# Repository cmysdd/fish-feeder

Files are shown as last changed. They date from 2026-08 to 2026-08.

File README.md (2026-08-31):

# ESP8266 + MixIO 远程鱼食投喂器

这是一个不自建服务器、不使用数据库、没有视频功能的远程鱼食投喂器。手机打开自己设计的网页，网页通过 MixIO 的 MQTT over WebSocket 接口发送命令；ESP8266 连接 MixIO MQTT 后驱动 MG90S 舵机完成投喂。

```text
手机自定义网页
    │ WSS 8084（加密）
    ▼
MixIO 免费主站
    ▲
    │ MQTT 1883 + HMAC 命令签名
    │
ESP8266 ── MG90S 舵机 ── 旋转量杯投喂机构
```

GitHub Pages 只负责免费托管静态 HTML、CSS 和 JavaScript，不运行后端函数。网页外观、按钮、状态显示和操作记录全部由本项目控制，不需要使用 MixIO 自带项目页面。

## 已实现功能

- 手机网页点击“立即投喂”执行一次完整动作
- 网页默认使用180°定位舵机，也可切换360°连续旋转舵机；两种模式都支持“去程→停留→回程”动作，180°模式可设置方向、角度和去/回程时间，参数保存在设备 EEPROM
- 最多 6 条设备本地定时计划，可设置时间、星期和启停状态；每条计划每次执行一次动作
- 定时计划保存在 ESP8266 EEPROM，手机关机或网页关闭后仍会执行
- MixIO WSS 实时连接和设备在线状态
- Wi-Fi 信号、剩余内存、固件版本、最近投喂时间
- 首次上电自建配网热点，Wi-Fi 凭据保存到 ESP8266 闪存
- 正常在线时从网页打开局域网设置页修改 Wi-Fi
- Wi-Fi 失效自动回退配网热点，支持双击 RST 强制重置
- 手机本地保存最近 30 条操作记录
- 每条命令带 UUID、签发时间、45 秒有效期和 HMAC-SHA256 签名
- ESP8266 EEPROM 保存最近命令、定时计划、最近投喂时间和 24 小时执行次数
- 防重复命令、防离线旧命令、防短时间连续投喂
- MQTT 断线自动重连、遗嘱消息和状态查询
- 舵机执行前先保存安全状态，执行中断电也不会重复运行同一命令
- 参数面板提供签名的“测试当前舵机”命令，不占用投喂次数，便于排查180°舵机接线和角度设置
- 多手机私密授权链接，导入后自动清除地址栏凭据
- 移动端计划卡片、操作提示、回到前台自动刷新和成功振动反馈

## 文档入口

- [完整项目方案](docs/project-plan.md)
- [硬件采购、供电、接线和机械结构](docs/hardware.md)
- [180° SG90 可打印机械结构](mechanical/README.md)
- [MixIO 注册、项目和主题配置](docs/mixio-setup.md)
- [GitHub Pages 部署、Arduino 烧录和首次联调](docs/deployment.md)
- [MQTT 消息协议和安全设计](docs/protocol.md)
- [测试与验收清单](docs/test-plan.md)

## 工程目录

```text
index.html                         手机控制台页面
styles.css                        响应式界面样式
app.js                            MixIO WSS、签名、状态和历史记录
.github/workflows/deploy-pages.yml GitHub Pages 自动部署
firmware/esp8266_fish_feeder/     ESP8266 Arduino 固件
docs/                             完整实施文档
```

## 最短落地路径

1. 购买 NodeMCU ESP8266、MG90S、5V 2A 电源和 1000uF 电容。
2. 注册 MixIO 账号并创建私有账号项目，记录用户名、项目名和项目密码。
3. 在第一台手机的“手机授权”中填写项目密码和命令签名密钥。
4. 其他可信手机可通过“复制授权链接”一次性导入相同配置；链接等同于钥匙，不要公开。
5. 按文档接线，烧录固件；Wi-Fi 不写进代码，首次上电用设备热点配置。
6. 把本目录推送到 GitHub，启用 GitHub Pages，手机使用生产 HTTPS 地址。
7. 在网页新增定时计划，等待设备回传并关闭网页验证自动执行。
8. 完成至少 100 次空载和装粮测试后再无人值守运行。

## 成本与限制

软件路线可以不产生固定月费，但 MixIO 和 GitHub Pages 的免费政策可能调整。硬件预计约 45～100 元，取决于是否已有 ESP8266、电源和机械外壳。

MixIO 为 ESP8266 提供的标准 MQTT 端口是 1883，设备到 MixIO 的传输不加密。本项目用额外的 HMAC 命令签名防止伪造投喂命令，但不能隐藏状态数据，也不能阻止网络层拒绝服务。更高安全等级需要自建 TLS MQTT、家庭 VPN，或改用能够稳定运行 WSS/TLS 的方案。

“投喂完成”表示舵机动作序列完成，不代表传感器已经确认鱼粮落下。长期无人值守版本应增加落料检测或称重反馈。

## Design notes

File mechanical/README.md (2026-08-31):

# SG90 180 度定量鱼食器机械结构 v2

这是本项目可直接打印的机械结构，使用 SG90 180 度定位舵机和偏心定量转盘：

```text
关闭位：料仓 -> 进粮口 -> 转盘定量孔
投喂位：转盘旋转 180 度 -> 定量孔对准落粮口 -> 导流嘴 -> 鱼缸
复位：  转盘反向旋转 180 度，重新装满定量孔
```

## 直接打印的 STL

将 [`stl`](stl) 文件夹发给打印者即可。里面是 6 个独立、已经按打印方向摆放的零件：

- `base.stl`：转盘底座，90 x 90 x 13 mm
- `rotor.stl`：固定容积转盘，直径 60.8 mm、厚 9 mm
- `hopper.stl`：约 600 mL 鱼粮仓和腔体上盖
- `lid.stl`：带防雨外沿的可拆上盖
- `servo_bracket.stl`：SG90 穿板支架，带安装调节槽
- `outlet_chute.stl`：压入式落粮导流嘴

这些 STL 均已检查为封闭、单体、法线一致的网格。不要把装配预览导出后打印。

参数化源文件是 [`fish_feeder_v1.scad`](fish_feeder_v1.scad)。以后要改容量或间隙时，用 OpenSCAD 修改后重新导出。默认定量孔直径 19 mm、深 9 mm，几何容积约 2.55 mL。

## 打印要求

优先用 PETG；长期室外日晒建议 ASA。PLA 只适合室内试装。

- 0.4 mm 喷嘴，0.20 mm 层高
- 底座、转盘、舵机支架：4 道墙、5 层顶底、40% 填充
- 料仓、盖子、导流嘴：3 道墙、5 层顶底、20% 填充
- 不缩放模型，单位必须是 mm
- 所有 STL 已放到打印平面，通常不需要支撑
- 料仓需要至少 120 x 100 mm 的打印平台
- 转盘与底座优先一起打印，材料和收缩率应保持一致

鱼粮接触件不等于食品级。打印后清理毛刺和线丝；需要更严格的食品接触要求时，加可拆洗的食品级内衬，不要在粮道里使用会脱落的涂层。

## 五金

- SG90 180 度定位舵机 1 个
- SG90 原装圆形或十字舵机臂 1 个，中心螺丝 1 个
- M3 x 30 螺丝、垫片和防松螺母各 4 个，用于夹紧料仓法兰、底座和舵机支架
- M2 x 8 螺丝和螺母 2 个，用于固定 SG90 耳片
- M2 x 6 自攻螺丝 2 个，用于把原装舵机臂固定到转盘底部
- 0.5 mm PET 垫片或薄食品级硅胶片，用于需要时微调转盘轴向间隙
- 食品级中性硅胶少量，只用于固定导流嘴外缘，不进入粮道
- 1000 uF 电解电容 1 个，靠近舵机 5V 和 GND
- IP65 成品防水盒 1 个，单独容纳 NodeMCU、电源接线和电容

## 装配

1. 将 SG90 从舵机支架下方穿入，输出轴对准底座中心。用两个 M2 螺丝穿过舵机耳片和支架调节槽固定，暂时不要拧死。
2. 用网页把舵机移动到关闭角度，建议先设为 10 度。安装原装舵机臂，确认舵机不会顶到机械限位。
3. 把舵机支架放在底座下方。输出轴和舵机臂从底座中心孔进入转盘腔。
4. 将转盘放入圆形腔体，定量孔朝向料仓侧的进粮位置。舵机臂嵌入转盘底部 32.5 mm 凹槽，用两颗 M2 x 6 自攻螺丝固定。
5. 手动检查转盘四周间隙。默认径向间隙 0.65 mm，上下各约 0.5 mm；转盘必须能转动，但不能明显上下晃动。
6. 放上料仓，使法兰孔、底座孔和支架孔对齐。四颗 M3 x 30 螺丝从上到下穿过，使用垫片和防松螺母均匀锁紧。
7. 把导流嘴从底座下方压入落粮口。试装合适后，只在外圈接缝点少量中性硅胶，保持内部粮道干净。
8. 装上盖子。电子部分放入旁边的 IP65 盒，舵机线和电源线通过 PG7/PG9 防水接头进入。

## 首次校准

1. 空仓测试：网页选择 180 度舵机，关闭角度先设 10 度，投喂角度先设 170 度，去程和回程各 1000 ms。
2. 检查关闭位：转盘定量孔必须完整位于料仓进粮口下方。
3. 检查投喂位：转盘转动后，定量孔必须完整位于底座落粮口上方。
4. 若两个位置均偏向同一侧，松开舵机臂中心螺丝，重新安装舵机臂；不要用软件角度强行顶住舵机限位。
5. 加入少量鱼粮连续测试 20 次。若转盘刮擦，用 0.5 mm PET 垫片微调料仓法兰；若颗粒进入转盘边缘，先清理毛刺，不要盲目扩大间隙。
6. 对 20 次投喂称重，确认平均重量后再装满粮仓。鱼粮密度不同，2.55 mL 不等于固定克数。
7. 装粮连续运行至少 100 次，确认不夹粮、舵机不过热、ESP8266 不重启，再进行无人值守测试。

## 打印前必须确认

SG90 克隆件的外壳、耳片孔距和输出轴高度可能相差 0.5-1.5 mm。建议先让朋友只打印 `servo_bracket.stl` 和 `rotor.stl` 做舵机试装，再打印其余大件。若舵机轴高度不足，可在支架与底座之间加薄垫片；若舵机臂与转盘凹槽不匹配，应修改源文件中的凹槽尺寸，不能强行压入。

这版没有位置或落料传感器，网页显示“动作完成”代表舵机程序执行完成，不代表鱼粮一定落下。无人长期运行前仍需做堵粮和断电恢复测试。

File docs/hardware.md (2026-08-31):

# 硬件采购、供电、接线和机械结构

## 1. 最小采购清单

| 数量 | 模块 | 推荐规格 | 参考用途 |
|---:|---|---|---|
| 1 | ESP8266 开发板 | NodeMCU ESP-12E/ESP-12F，CH340 或 CP2102 | Wi-Fi 和逻辑控制 |
| 1 | 舵机 | SG90 180°定位舵机（推荐）或360°连续旋转舵机 | 驱动旋转量杯 |
| 1 | 电源 | 稳压 5V 2A | 给开发板和舵机供电 |
| 1 | 电解电容 | 1000uF，耐压 10V 或更高 | 抑制舵机启动压降 |
| 若干 | 杜邦线或接线端子 | 按模块接口选择 | 信号和供电连接 |
| 1 | USB 数据线 | 必须支持数据传输 | 固件烧录 |
| 1 | 投喂机械件 | 旋转量杯、粮仓、固定支架 | 定量落料 |

连续旋转舵机只能控制方向和速度，不能直接知道绝对角度，因此本项目用运行时间估算角度并自动反转回位；如果需要精确定位，选择180°定位舵机或增加位置传感器。若机械负载较大，选带金属齿轮、额定5V的连续舵机。

## 2. 接线表

舵机常见线色（以你手上标签为准）：

| 舵机线 | 连接位置 |
|---|---|
| 棕色或黑色 | 5V 电源 GND |
| 红色 | 5V 电源正极 |
| 橙色或黄色 | NodeMCU D1（GPIO5） |

NodeMCU GND 必须与舵机电源 GND 连接在一起，否则舵机信号没有共同参考电位。

```text
NodeMCU D1 / GPIO5 ───────────── 舵机信号线

5V 电源正极 ──┬─────────────── 舵机红线
              └─────────────── NodeMCU VIN/5V

5V 电源负极 ──┬─────────────── 舵机棕/黑线
              └─────────────── NodeMCU GND

1000uF 电容接在舵机附近的 5V 与 GND 之间
电容正极接 5V，带条纹的负极接 GND
```

ESP8266 的 3.3V GPIO 信号通常可以直接控制 MG90S，但不能使用 ESP8266 的 3.3V 引脚给舵机供电。MG90S 堵转或快速启动时电流可能明显升高，必须使用稳定的外部 5V 电源。

### 配网重置按键

本固件默认使用 NodeMCU 的 `FLASH` 按键（GPIO0/D3）作为强制配网输入，不需要额外购买按键。设备正常运行时，按住 `FLASH`，再按一下 `RST`，松开后会清除已保存 Wi-Fi 并开启 `fish-feeder-xxxx` 配置热点。也可以快速连续按两次 `RST` 触发同样的配网模式。不要在烧录时长按 `FLASH`，否则开发板可能进入下载模式。

如果你的板子没有可用的 `FLASH` 键，可以在 `D3` 和 `GND` 之间接一个常开轻触按键，并在上电/复位时按住它。

## 3. 烧录和正式运行时的供电

### 烧录阶段

1. USB 只给 NodeMCU 供电和传输数据。
2. 舵机使用独立 5V 电源。
3. 舵机电源 GND 与 NodeMCU GND 共地。
4. 不要把外部 5V 正极再接到 NodeMCU VIN，避免两路 5V 电源互相回灌。

### 正式运行

拔掉电脑 USB 后，可以使用同一只 5V 2A 电源并联给 NodeMCU VIN/5V 和舵机供电。不同 NodeMCU 克隆板的电源保护方式不同，正式运行时不要同时插着电脑 USB 和外部 VIN 供电。

## 4. 机械结构选择

### 推荐：旋转量杯

```text
上方粮仓
   ↓
[量杯处于装粮位置]  ← SERVO_CLOSED_ANGLE
   │ 舵机旋转
[量杯处于倒粮位置]  ← SERVO_OPEN_ANGLE
   ↓
鱼缸
```

量杯的容积决定每次动作的鱼粮量。当前网页每次只执行一次装粮—倒粮—回位动作。

优点：

- 出粮量主要由量杯容积和机械结构决定。
- 180°普通舵机即可完成。
- 回位后自动准备下一份。
- 软件不需要根据鱼粮流速计算开门时间。

### 不推荐：单纯翻板闸门

闸门结构虽然最简单，但每次落料量会受颗粒大小、仓内压力、湿度和打开时间影响。鱼粮受潮后容易形成架桥，舵机动作完成却没有实际落料。

## 5. 舵机角度校准

本项目针对你的 180° SG90，推荐使用仓库中的参数化机械结构：[mechanical/README.md](../mechanical/README.md)。它使用固定容积转子量杯，转子孔先在上方装粮，再转到下方出粮口，避免 SG90 直接承受整仓鱼粮压力。

固件默认值（也可以在网页“投喂参数”中修改并保存到设备）：

```cpp
#define SERVO_CLOSED_ANGLE 90
#define SERVO_OPEN_ANGLE 180
#define SERVO_OPEN_MS 550
#define SERVO_SETTLE_MS 450
#define SERVO_MODE_DEFAULT 1
#define SERVO_POSITIONAL_MOVE_MS 1000UL
#define SERVO_ACTION_PAUSE_MS 1000UL
#define SERVO_POSITIONAL_RETURN_MS 1000UL
#define SERVO_CONTINUOUS_TURN_DEGREES 90
#define SERVO_CONTINUOUS_MS_PER_REV 4000UL
#define SERVO_CONTINUOUS_FORWARD_US 1700
#define SERVO_CONTINUOUS_REVERSE_US 1300
#define SERVO_CONTINUOUS_STOP_US 1500
```

网页默认使用180°定位舵机模式。对于机械转子量杯，先把关闭角度校准到转子孔对准上方装粮口，再把打开角度校准到孔对准下方出粮口，建议先用10°和170°，避免长期顶住舵机两端。180°定位模式使用“起始位置 + 方向 + 相对角度”，并以小步插值控制去程和回程时间。顺逆时针会受舵机安装方向影响，首次必须空载确认。360°连续舵机仍可手动切换，但不适合这套精确定量转子。

当前固件在180°模式使用500～2400us定位脉宽，以覆盖常见SG90的完整机械行程。保存180°模式参数时，设备会立即移动到起始位置；投喂时再执行“去程→停留→回程”。设定时间不能突破舵机自身速度上限：如果负载下90°实际至少需要1.3秒，即使网页填写1秒也无法让舵机物理上更快。如果网页测试完全没有动作，烧录 `firmware/servo_diagnostic/servo_diagnostic.ino` 排查。

第一次测试时不要安装舵臂：

1. 连续模式烧录后上电，舵机应保持停止，不应自行转动。
2. 先不装鱼粮，设置一圈耗时并测试180°转动，按实际转速微调。
3. 安装量杯后，用少量鱼粮测试一次出粮，调整转动角度和方向。
4. 如果切换到180°模式，断电后安装舵臂到关闭位置，再逐步调整两个定位角度。
5. 连续舵机停止脉宽通常约1500us；若仍慢慢转，用高级校准把停止脉宽调整到实际静止值。

不要依靠舵机堵转作为机械限位。长期堵转会导致电流上升、齿轮磨损和 ESP8266 重启。

## 6. 粮仓与环境

- 粮仓使用食品接触安全、无异味的材料。
- 增加密封盖和干燥剂空间，避免鱼缸水汽进入。
- 出粮口远离过滤泵水花和增氧气泡。
- 电路板和接线端子放在鱼缸水线以上。
- 电源线做拉力缓解，不能依靠杜邦线悬挂设备。
- 正式使用时采用螺丝端子或焊接，不使用松动的面包板连接。

## 7. 建议的第二阶段传感器

| 传感器 | 作用 | 优先级 |
|---|---|---|
| 槽型光电开关 | 检测量杯是否回到原位 | 高 |
| 对射光电或落料传感器 | 判断是否真的有鱼粮落下 | 高 |
| 1kg 称重传感器 + HX711 | 估算粮仓余量 | 中 |
| DS18B20 防水探头 | 读取鱼缸水温 | 中 |
| 漏水传感器 | 鱼缸附近积水报警 | 中 |

第一版没有位置和落料反馈，因此网页中的“完成”仅表示舵机动作序列执行完毕。

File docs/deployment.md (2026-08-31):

# 从烧录到 GitHub Pages 上线：完整部署教程

本项目采用“手机网页直连 MixIO + ESP8266 本地执行”的结构。GitHub Pages 只托管静态网页，不保存 MixIO 项目密码、命令签名密钥、计划表或操作记录。定时计划保存在 ESP8266 的 EEPROM 中，手机和网页关闭后仍会运行。

## 1. 当前项目已经准备好的内容

当前工作区已经完成：

- MixIO 用户名、项目名、项目密码和命令签名密钥配置。
- MixIO 项目密码和命令签名密钥写入本机私密 `config.h`。
- Wi-Fi 不写入源码，首次上电通过设备自己的配置热点写入闪存。
- `config.h` 已加入 `.gitignore`，不会提交到 Git。
- 私密 `config.h` 已加入 `.gitignore`，不会上传到 GitHub。
- 网页支持手动投喂、设备状态、最多 6 条定时计划和多手机授权。

你不需要修改固件里的 Wi-Fi 字符串；首次上电按下面的配网步骤填写。不要把私密 `config.h` 发到公开仓库或论坛。

## 2. 安装 Arduino IDE 和开发板

1. 安装 Arduino IDE 2.x。
2. 打开“文件 → 首选项”。
3. 在“附加开发板管理器网址”加入：

```text
https://arduino.esp8266.com/stable/package_esp8266com_index.json
```

4. 打开“工具 → 开发板 → 开发板管理器”。
5. 搜索并安装 `esp8266 by ESP8266 Community` 的稳定 3.x 版本。
6. 打开“库管理器”，安装：

| 库 | 建议版本 |
|---|---|
| ArduinoJson by Benoit Blanchon | 6.21.x，或确认兼容的更新版 |
| PubSubClient by Nick O'Leary | 2.8 或更新稳定版 |

`Servo`、`EEPROM`、`ESP8266WiFi`、NTP 时间和 BearSSL 随 ESP8266 开发板包提供。

## 3. 准备私密固件配置

打开：

```text
firmware/esp8266_fish_feeder/config.h
```

MixIO 信息和命令签名密钥已经在本机私密 `config.h` 中。Wi-Fi 两行保持空字符串即可：

```cpp
#define WIFI_SSID ""
#define WIFI_PASSWORD ""
```

注意：

- ESP8266 只能连接 2.4GHz Wi-Fi。
- Wi-Fi 名称区分大小写。
- 如果路由器把 2.4GHz 和 5GHz 合并为同一名称，一般可以使用；首次联调失败时建议临时分开名称。
- 其他 MixIO 和签名配置已经写好，不要只改固件而不更新授权手机。

## 4. 接线和烧录

首次烧录建议先断开舵机，只连接 NodeMCU USB：

1. 使用支持数据传输的 USB 线连接电脑。
2. Arduino IDE 打开：

```text
firmware/esp8266_fish_feeder/esp8266_fish_feeder.ino
```

3. 开发板选择 `NodeMCU 1.0 (ESP-12E Module)`。
4. 选择正确的 COM 端口。
5. Upload Speed 先选择 `115200`。
6. CPU Frequency 使用 `80 MHz`。
7. Flash Size 使用开发板默认的 4MB 选项即可。
8. 点击“验证”；成功后点击“上传”。
9. 打开串口监视器，波特率选择 `115200`。

首次没有 Wi-Fi 时，串口日志应包含：

```text
Wi-Fi configuration mode
Setup SSID: fish-feeder-xxxx
Open: http://192.168.4.1
```

填写 Wi-Fi 后，设备重启并连接成功时日志应包含：

```text
ESP8266 servo fish feeder starting
Wi-Fi connected, IP: ...
Connecting to MixIO MQTT...
MixIO MQTT connected
```

升级到当前固件时 EEPROM 数据结构会自动初始化一次；如果结构版本变化，旧的测试计数和计划被清空属于正常现象。

## 5. 首次配网和重置配网

1. 烧录后上电，手机连接设备热点 `fish-feeder-xxxx`，密码是 `fish8266`。
2. 打开 `http://192.168.4.1`；若手机弹出“此网络无互联网”，选择继续保持连接。
3. 填写家里的 2.4GHz Wi-Fi 名称和密码，点击“保存并连接”。设备会把信息写入 EEPROM/闪存并自动重启。
4. 以后断电、重启都不需要重新填写。正常联网时，网页状态卡片会显示局域网 IP，点击“打开 Wi-Fi 设置”即可在同一家庭 Wi-Fi 内修改。
5. 如果旧 Wi-Fi 改名或失效，设备尝试约 20 秒后自动开启配置热点。也可以双击 NodeMCU 的 `RST`，或按住 `FLASH` 再按 `RST`，清除旧凭据并进入配网。
6. 配网设置页是局域网管理页；不要把设备热点密码和局域网地址发到公共群组。

注意：设备已经成功 NTP 校时后，即使 MixIO 暂时不可达，已保存的计划仍可继续执行；如果设备重启后完全没有网络，时间尚未校准，计划会等联网校时后再执行。

## 6. 连接 MG90S 舵机

NodeMCU D1/GPIO5 连接舵机信号线。舵机使用独立稳定的 5V 2A 电源，NodeMCU GND 和舵机电源 GND 必须共地。舵机附近并联一个 1000uF 电解电容。

首次动作测试不要安装鱼粮：

1. 先空载通电。
2. 确认舵机回到关闭角度后停止。
3. 如果舵机持续嗡鸣，立即断电并缩小开关角度。
4. ESP8266 在舵机动作时重启，优先检查 5V 电源、电容和共地，不要用软件延时掩盖供电问题。

## 7. 本地预览网页

当前项目可通过本地静态服务器预览。浏览器地址类似：

```text
http://127.0.0.1:4173/
```

本地 HTTP 页面可能因浏览器安全策略无法使用剪贴板或 Web Crypto 的部分能力，最终测试使用 GitHub Pages 提供的 HTTPS 地址。

## 8. 部署到 GitHub Pages

网页没有构建步骤、数据库和环境变量。项目已经包含 `.github/workflows/deploy-pages.yml`，推送到 `main` 分支后会自动发布。

### 8.1 创建仓库并上传

1. 在 GitHub 新建一个仓库，例如 `fish-feeder`。
2. 想零成本使用 GitHub Pages 时，仓库可设为 `Public`；私密 `firmware/esp8266_fish_feeder/config.h` 仍绝不能提交。若使用私有仓库，请确认你的 GitHub 账号计划支持 Pages。
3. 在 PowerShell 中执行：

```powershell
cd C:\Users\Administrator\Desktop\硬件开发\fish-feeder
git init
git branch -M main
git add .
git status
git commit -m "Initial fish feeder page"
git remote add origin https://github.com/你的用户名/fish-feeder.git
git push -u origin main
```

执行 `git status` 时，不能看到以下文件：

- `firmware/esp8266_fish_feeder/config.h`
- 任何包含 MixIO 项目密码或命令签名密钥的私密备份文件

### 8.2 启用 GitHub Pages

1. 打开 GitHub 仓库的 `Settings → Pages`。
2. 在 `Build and deployment` 中选择 `GitHub Actions`。
3. 回到 `Actions` 页面，等待 `Deploy fish feeder page` 工作流完成。
4. 部署地址一般是：

```text
https://你的用户名.github.io/fish-feeder/
```

以后更新网页只需：

```powershell
git add .
git commit -m "Update fish feeder page"
git push
```

## 9. 第一台手机授权

1. 用手机打开 GitHub Pages 的 HTTPS 地址。
2. 点击右上角“手机授权”。
3. 用户名和项目名已经预填。
4. 输入 MixIO 项目密码。
5. 输入与固件 `COMMAND_SECRET` 完全一致的命令签名密钥。
6. 保持“保存在当前浏览器中”选中。
7. 点击“保存并连接”。

这些信息只写入当前域名的浏览器存储，并由手机直接用于连接 MixIO WSS。GitHub Pages 不会收到这些字段。

本地预览地址与 GitHub Pages 地址属于不同网站，浏览器存储不会互通，因此生产地址第一次打开时仍需授权一次。

## 10. 授权其他手机

第一台手机连接成功后：

1. 打开“手机授权”。
2. 点击“复制授权链接”。
3. 通过私聊发送给可信的人。
4. 对方打开链接后，网页自动把配置保存到对方手机。
5. 地址栏中的 `#config=...` 会立即被清除。

授权链接本身等同于项目密码和签名密钥。不要发送到群聊、朋友圈、公开笔记或短链接平台。需要撤销所有旧授权时，同时更换 MixIO 项目密码和命令签名密钥，然后重新烧录并重新授权手机。

## 11. 测试手动投喂

1. 页面顶部 MixIO 显示“已连接”。
2. 投喂器显示“在线”。
3. 点击“请求状态”，检查 Wi-Fi 信号、固件版本和设备时间。
4. 不放鱼粮，点击“立即投喂”；每次点击只执行一次完整动作。
5. 页面应依次显示命令发送、设备执行和投喂完成。
6. 一分钟内再次投喂，应被安全间隔拒绝。
7. 完成空载测试后，再安装少量鱼粮测试真实出粮量。

## 11.1 设置舵机角度和投喂限制

设备升级到固件 `1.5.3` 后，网页会显示完整动作序列和“测试当前舵机”按钮：

1. 先不要安装粮仓负载，打开“请求状态”确认固件版本为 `1.5.3`。
2. 180° SG90 设置关闭位置、方向、单程角度、去程时间、到位停留和回程时间。机械转子量杯建议先从关闭10°、打开170°开始，再按实际安装位置微调。
3. 如果切换到360°连续舵机，再设置方向、估算转动角度和一圈耗时。例如90°且一圈4000毫秒，单程约运行1000毫秒；再设置到位停留和是否反转回位。
4. 点击“保存到投喂器”，等待页面显示“已保存到投喂器”；然后点击“测试当前舵机”。测试不会计入投喂次数，适合先观察 SG90 是否从关闭角度转到投喂角度再回位。
4. 设置两次投喂最短间隔和每日最大次数。
5. 点击“保存到投喂器”，等待设备确认；网页关闭或设备断电后参数仍保留。
6. 连续舵机若停止后仍慢慢转，展开“连续舵机方向/停止校准”，调整停止脉宽；若方向相反，切换投喂方向。

## 12. 设置和验证定时投喂

定时计划保存在 ESP8266，而不是手机：

1. 点击“添加计划”。
2. 时间设置为当前北京时间之后 3～5 分钟。
3. 选择执行星期；每次到点只执行一次完整动作。
4. 保持计划启用，点击“保存到投喂器”。
5. 等待“定时计划已保存到投喂器”的提示。
6. 点击“请求状态”，确认计划仍显示在页面中。
7. 完全关闭网页或关闭手机屏幕。
8. 到达设定时间后观察舵机是否自动执行。
9. 重新打开网页，检查最近投喂时间、来源和 24 小时执行次数。

注意：

- 固件固定使用北京时间 UTC+8，不跟随手机所在时区。
- 设备上电后必须至少联网完成 NTP 校时，时间未就绪时不会盲目执行计划。
- 同一分钟内有重叠计划时，最短投喂间隔会让后续计划跳过。
- 手动投喂发生在定时计划前一分钟内，计划也可能因安全间隔被跳过。
- 达到 24 小时最大次数后，定时计划不会突破上限。

## 13. 常见故障

| 现象 | 检查内容 |
|---|---|
| 网页一直显示 MixIO 连接中 | 项目密码、手机网络、MixIO WSS 8084 是否可达 |
| MixIO 已连接但设备离线 | 家庭 Wi-Fi、MQTT 1883、ESP8266 串口日志和供电 |
| `invalid_signature` | 手机与固件的命令签名密钥不一致 |
| `clock_not_ready` | 等待 NTP 校时，检查 DNS 和互联网连接 |
| 计划或参数保存失败 | 设备是否在线、固件是否已升级到 1.5.3 |
| 舵机测试无动作 | 检查状态中的舵机模式和角度，确认点击测试后收到确认；再检查 SG90 红线5V、棕线GND、橙线D1，并确认外部电源与 NodeMCU 共地 |
| 计划到点未执行 | 星期、启用状态、北京时间、安全间隔和 24 小时上限 |
| 页面显示计划被安全间隔跳过 | 前一分钟内发生过手动或其他定时投喂 |
| 舵机动作时 ESP8266 重启 | 5V 电源不足、没有共地或缺少大电容 |
| 显示完成但没有鱼粮 | 量杯卡住、鱼粮受潮架桥；当前版本没有落料传感器 |

## 14. 正式上线前验收

- 连续运行至少 7 天。
- 完成至少 100 次空载动作和 50 次装粮动作。
- 实测一次动作的出粮量，确认量杯容积适合鱼粮。
- 测试断电重启、路由器重启、MixIO 临时断线和手机流量访问。
- 检查计划在网页关闭时仍能执行。
- 检查断电发生在舵机动作中时不会在同一天重复执行同一计划。
- 使用防潮外壳、可靠端子和稳定电源后再长期无人值守。

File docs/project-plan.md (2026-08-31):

# 完整项目方案

## 1. 项目目标

开发一台家用远程鱼食投喂器：鱼缸附近有 2.4GHz Wi-Fi，用户在户外通过手机浏览器打开自己的控制页面，查看设备在线状态并手动投喂。第一版不包含视频，也不要求原生接入米家。

设计约束：

- 不购买云服务器，不支付固定月费。
- 不使用 MixIO 自带的项目界面。
- 使用现有 ESP8266 Wi-Fi 开发板。
- 使用简单、易接线的舵机机构。
- 网络异常、重复消息和设备重启不能造成明显的重复投喂风险。

## 2. 最终技术路线

| 层级 | 选型 | 职责 |
|---|---|---|
| 手机界面 | 原生 HTML/CSS/JavaScript | 自定义控制、状态、历史和连接设置 |
| 静态托管 | GitHub Pages + Actions | 提供 HTTPS 页面，不运行后端函数 |
| 消息平台 | MixIO 免费主站 | MQTT 消息转发和在线连接 |
| 浏览器通信 | MQTT.js + WSS 8084 | 加密连接 MixIO，发布命令、订阅状态 |
| 设备通信 | PubSubClient + MQTT 1883 | ESP8266 接收命令、发布确认和状态 |
| 命令认证 | HMAC-SHA256 | 防止只有 MixIO 项目密码的人伪造投喂命令 |
| 执行机构 | 180°定位舵机（默认）或360°连续舵机 | 定位模式按目标角度控制，连续模式按时间估算角度 |
| 状态保存 | ESP8266 EEPROM | 保存防重放、投喂限额、舵机位置和运行参数 |

不再使用 Supabase、GitHub API、数据库和定时轮询。GitHub Actions 只负责发布静态文件；手机页面和设备都主动连接 MixIO，命令延迟通常由 MQTT 网络决定。

网页的“投喂参数”可选择360°连续或180°定位模式。连续模式可设置转动角度、一圈耗时、正反转/停止脉宽和方向；定位模式可设置关闭/投喂角度。两种模式共用PWM信号和MQTT协议，参数通过 HMAC 签名命令传给设备，设备校验后写入 EEPROM，断电仍保留。

## 3. 数据流

```text
1. 手机网页连接 wss://mixio.mixly.cn:8084
2. ESP8266 连接 mixio.mixly.cn:1883
3. 双方订阅同一账号和项目下的主题
4. 手机生成 UUID 和 45 秒有效期
5. 手机使用共享密钥计算 HMAC-SHA256
6. ESP8266 校验签名、时间、重复编号和投喂限额
7. ESP8266 先写 EEPROM，再驱动舵机
8. ESP8266 发布 processing/completed/rejected 状态
9. 手机更新页面和本地历史记录
```

## 4. MQTT 主题

主题完整形式为 `MixIO用户名/项目名/主题名`。

| 主题名 | 方向 | 说明 |
|---|---|---|
| `feeder_cmd` | 手机 → 设备 | 带签名的投喂命令 |
| `feeder_ack` | 设备 → 手机 | 接收、完成或拒绝结果 |
| `feeder_state` | 设备 → 手机 | 遥测和安全状态，保留消息 |
| `feeder_online` | 设备 → 手机 | 在线状态和 MQTT 遗嘱，保留消息 |
| `feeder_query` | 手机 → 设备 | 请求立即上报状态 |

## 5. 设备状态机

```text
启动
 ├─ 初始化 EEPROM
 ├─ 舵机回到关闭角度
 ├─ 连接 Wi-Fi、同步 NTP
 └─ 连接 MixIO、订阅命令
           ↓
        等待命令
           ↓
    格式与签名校验
      ├─ 不通过 → rejected
      └─ 通过
           ↓
   时效/重复/限额校验
      ├─ 不通过 → rejected
      └─ 通过
           ↓
       EEPROM 预提交
           ↓
       processing 确认
           ↓
        舵机动作
      ├─ 完成 → completed
      └─ 异常 → failed
```

EEPROM 预提交是关键安全措施。如果舵机动作期间突然断电，设备重启后仍记得该命令已经被领取，不会再次执行同一个 MQTT 消息。

## 6. 机械方案

推荐使用“旋转量杯”，而不是仅按时间打开粮仓闸门：

- 关闭位置：量杯对准粮仓，装入一份鱼粮。
- 打开位置：舵机转动约 70～100°，量杯对准鱼缸并倒出。
- 回位：量杯返回粮仓，等待下一次投喂。
- 多份投喂：重复完整的打开—关闭循环。

这种结构的份量主要由量杯容积决定，受舵机速度和鱼粮流速影响较小。颗粒鱼粮最适合；薄片鱼粮需要更大的开口和防架桥设计。

## 7. 安全边界

本方案同时使用两类凭据：

1. MixIO 项目密码：允许连接项目并收发消息。
2. 命令签名密钥：只保存在手机浏览器和 ESP8266 固件中，用于证明命令来自你的页面。

即使 MixIO 项目密码在未加密的 1883 链路上被观察到，没有命令签名密钥也无法生成新的有效投喂命令。命令还必须在 45 秒内到达，重复 UUID 会被 EEPROM 拒绝。

仍然存在的风险：攻击者可能伪造设备状态、干扰 MQTT 连接或阻断网络。家庭自用第一版通常可以接受；商业产品不应使用这个安全等级。

## 8. 开发阶段

### 阶段 A：电气台架

- ESP8266 单独烧录，确认 Wi-Fi 和 MixIO 在线。
- 舵机独立 5V 供电，共地连接。
- 不安装鱼粮，校准关闭和打开角度。

### 阶段 B：机械样机

- 制作旋转量杯和粮仓。
- 测量每个循环的平均克数和误差。
- 连续运行至少 100 次，检查卡料、回位和舵机发热。

### 阶段 C：远程联调

- GitHub Pages 部署自定义网页。
- 使用手机流量测试远程投喂。
- 测试 Wi-Fi 中断、MQTT 重连、重复消息和命令过期。

### 阶段 D：长期运行

- 连续上电 7 天。
- 测试停电恢复、路由器重启和 MixIO 短时不可用。
- 加装防潮外壳、线缆固定和机械限位。

## 9. 后续扩展

- 增加光电落料检测，区分“舵机完成”和“实际落粮”。
- 增加称重传感器，显示粮仓余量。
- 增加 DS18B20 水温传感器。
- 增加本地定时投喂，断网仍可执行固定计划。
- 使用 Home Assistant 或 Matter 做家庭自动化桥接。
- 商业化时更换为 TLS MQTT、设备独立证书和正式 MIoT/Matter 认证。

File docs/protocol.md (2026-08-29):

# MQTT 消息协议和安全设计

## 1. 协议版本

所有 JSON 消息包含：

```json
{ "v": 1 }
```

增加不兼容字段时应提升版本号。ESP8266 接受版本 1 的手动投喂、计划更新和设备参数更新命令。

网页还提供 `servo_test` 测试命令。它使用当前已保存的舵机模式执行一次“关闭→投喂→关闭”动作（连续舵机按当前转动参数运行），不计入投喂次数和 24 小时上限；同样需要 HMAC 签名，适合空载排查接线和模式配置。

## 2. 投喂命令

主题：

```text
用户名/项目名/feeder_cmd
```

示例：

```json
{
  "v": 1,
  "id": "c61fdba6-8125-4d91-88af-685d92e2a951",
  "action": "feed",
  "portion": 1,
  "issued_at": 1786924800,
  "expires_at": 1786924845,
  "sig": "64位十六进制HMAC-SHA256"
}
```

字段：

| 字段 | 类型 | 说明 |
|---|---|---|
| `id` | UUID | 命令唯一编号 |
| `action` | 字符串 | 固定为 `feed` |
| `portion` | 整数 | 1～3 |
| `issued_at` | Unix 秒 | 手机签发时间 |
| `expires_at` | Unix 秒 | 命令过期时间，默认晚 45 秒 |
| `sig` | 十六进制字符串 | HMAC-SHA256 签名 |

网页使用 QoS 1、`retain=false` 发布。QoS 1 可能重复投递，因此不能把 MQTT 收到一次等同于执行一次，必须使用命令 UUID 去重。

## 3. 签名算法

签名原文严格按以下顺序拼接：

```text
v|id|action|portion|issued_at|expires_at
```

示例：

```text
1|c61fdba6-8125-4d91-88af-685d92e2a951|feed|1|1786924800|1786924845
```

以 `COMMAND_SECRET` 为密钥计算 HMAC-SHA256，再转换为小写十六进制。网页使用 Web Crypto，ESP8266 使用开发板包自带的 BearSSL。

命令签名密钥不会出现在 MQTT 消息中。它应使用至少 24 字节随机数据，网页默认生成 24 字节并显示为 48 位十六进制。

手动投喂联调测试向量：

```text
密钥：0123456789abcdef0123456789abcdef
原文：1|c61fdba6-8125-4d91-88af-685d92e2a951|feed|1|1786924800|1786924845
结果：a1e8a87a41f3f6174d81858926cd88daf73ecf57e9726f88c6fdd73a3eb4ce79
```

如果网页和固件对同一测试向量计算结果不同，不能继续进行真实投喂测试。

## 4. 定时计划更新命令

计划更新与手动投喂共用 `feeder_cmd` 主题，`action` 为 `set_schedule`：

```json
{
  "v": 1,
  "id": "75a2f5ec-ecc0-4ae8-9926-8b974eaef3e9",
  "action": "set_schedule",
  "schedule_data": "1,8,0,1,127;1,18,30,2,62",
  "issued_at": 1786924800,
  "expires_at": 1786924845,
  "sig": "64位十六进制HMAC-SHA256"
}
```

每条计划编码为 `enabled,hour,minute,portion,daysMask`，多条使用分号连接，空字符串表示清空全部计划。`daysMask` 从 bit 0 到 bit 6 依次代表周日到周六；`127` 表示每天，`62` 表示周一到周五，`65` 表示周末。最多保存 6 条。

计划命令签名原文：

```text
v|id|action|schedule_data|issued_at|expires_at
```

计划更新测试向量：

```text
密钥：0123456789abcdef0123456789abcdef
原文：1|75a2f5ec-ecc0-4ae8-9926-8b974eaef3e9|set_schedule|1,8,0,1,127;1,18,30,2,62|1786924800|1786924845
结果：e258c2b2586925871fbb7a7a1413f3eeb7b678b4ce2f9d7844b933eb34bfdef3
```

设备校验签名、时效和字段范围后，把整组计划写入 EEPROM。计划固定使用 UTC+8 北京时间执行。

## 5. 设备参数更新命令

设备参数更新与其它命令共用 `feeder_cmd` 主题，`action` 为 `set_config`。网页将参数编码为：

```text
舵机模式,起始角度,目标角度,连续转动角度,一圈耗时毫秒,正转脉宽,反转脉宽,停止脉宽,连续投喂方向,连续是否回位,180去程毫秒,到位停留毫秒,180回程毫秒,最短间隔秒数,每日最大份量,每日最大次数
```

例如 `0,90,180,90,4000,1700,1300,1500,0,1,1000,1000,1000,60,12,8`。模式 `1` 为360°连续旋转，按“连续转动角度 ÷ 360 × 一圈耗时”计算单程时间；回位字段为 `1` 时，在到位停留后反向运行同样时间。模式 `0` 为180°定位舵机，网页根据起始位置、方向和相对角度计算目标角度，固件按去程时间平滑移动，到位停留后再按回程时间返回。新版仍兼容旧版13字段和12字段参数，缺少的动作时间使用默认值。

签名原文为：

```text
v|id|set_config|config_data|issued_at|expires_at
```

## 6. 设备确认

主题：

```text
用户名/项目名/feeder_ack
```

示例：

```json
{
  "v": 1,
  "id": "c61fdba6-8125-4d91-88af-685d92e2a951",
  "device_id": "feeder-001",
  "action": "feed",
  "status": "completed",
  "portion": 1,
  "reason": "motor_sequence_completed",
  "ts": 1786924804
}
```

状态：

| 状态 | 说明 |
|---|---|
| `processing` | 命令通过校验，安全状态已写入 EEPROM，正在驱动舵机 |
| `completed` | 舵机动作序列完成 |
| `rejected` | 命令未执行，查看 `reason` |
| `failed` | 已领取命令，但执行过程报告失败 |
| `duplicate` | UUID 已处理，设备不会再次执行 |

拒绝原因：

| `reason` | 含义 |
|---|---|
| `invalid_payload` | JSON 字段或命令类型错误 |
| `invalid_portion` | 份量超出固件范围 |
| `invalid_schedule` | 定时计划字段、数量或日期掩码无效 |
| `invalid_config` | 设备参数超出固件允许范围 |
| `stale_schedule` | 计划更新时间早于设备已保存的版本 |
| `stale_config` | 参数更新时间早于设备已保存的版本 |
| `clock_not_ready` | NTP 尚未同步，无法验证时效 |
| `command_expired` | 命令太旧、已过期或时间异常 |
| `invalid_signature` | HMAC 签名不匹配 |
| `duplicate_command` | 相同 UUID 已处理 |
| `cooldown` | 距上次投喂时间过短 |
| `daily_limit` | 24 小时窗口份量达到上限 |
| `servo_failed` | 舵机对象无法启动或动作失败 |
| `schedule_updated` | 定时计划已写入 EEPROM |
| `config_updated` | 设备参数已写入 EEPROM |

## 7. 设备状态

主题：

```text
用户名/项目名/feeder_state
```

此消息使用 `retain=true`，网页刚连接时可以立即获得最近状态。

```json
{
  "v": 1,
  "online": true,
  "device_id": "feeder-001",
  "firmware": "1.3.1",
  "rssi": -58,
  "wifi_ssid": "home-2.4g",
  "ip": "192.168.1.88",
  "config_url": "http://192.168.1.88/",
  "free_heap": 31200,
  "uptime_s": 3600,
  "ts": 1786924800,
  "clock_ready": true,
  "last_feed_at": 1786924700,
  "last_feed_source": "schedule",
  "portions_24h": 2,
  "feeds_24h": 1,
  "max_portions_24h": 12,
  "max_feeds_24h": 8,
  "min_interval_seconds": 60,
  "servo_closed_angle": 12,
  "servo_open_angle": 92,
  "servo_mode": 1,
  "continuous_turn_degrees": 180,
  "continuous_ms_per_rev": 2000,
  "continuous_forward_us": 1700,
  "continuous_reverse_us": 1300,
  "continuous_stop_us": 1500,
  "continuous_direction": 0,
  "continuous_return": true,
  "positional_move_ms": 1000,
  "action_pause_ms": 1000,
  "positional_return_ms": 1000,
  "last_error": "",
  "timezone_offset_minutes": 480,
  "schedules": [
    { "enabled": true, "hour": 8, "minute": 0, "portion": 1, "days_mask": 127 }
  ]
}
```

状态每 60 秒发布一次，投喂完成、命令拒绝和网页请求状态时也会立即发布。

定时任务因安全间隔或每日上限被跳过时，`last_error` 分别为 `schedule_cooldown` 或 `schedule_daily_limit`。

## 8. 在线状态和遗嘱

主题：

```text
用户名/项目名/feeder_online
```

设备连接成功后发布：

```json
{ "v": 1, "online": true, "device_id": "feeder-001", "ts": 1786924800 }
```

连接意外中断时 MixIO 发布 MQTT Last Will：

```json
{ "v": 1, "online": false, "device_id": "feeder-001", "ts": 0 }
```

网页还设置了 180 秒状态超时。即使遗嘱没有及时到达，长期没有任何设备消息也会显示离线。

## 9. 状态查询

网页向 `feeder_query` 发布：

```json
{ "action": "status", "requested_at": 1786924800 }
```

查询不触发执行机构，因此没有签名。设备收到后立即重新发布 `feeder_state`。

## 10. 防重放流程

设备按顺序检查：

1. JSON 和协议版本。
2. UUID 格式和份量范围。
3. NTP 时间是否有效。
4. 签发时间、过期时间和最大有效期。
5. HMAC-SHA256 签名。
6. UUID 是否与 EEPROM 中最近命令一致。
7. 最短投喂间隔。
8. 24 小时份量上限。

全部通过后，设备先把 UUID、投喂时间和份量写入 EEPROM，然后才驱动舵机。这个顺序选择“可能漏投一次，也不重复投喂”，更适合鱼食投喂安全。

## 11. 定时执行流程

设备每个本地分钟检查一次计划：

1. NTP 时间必须有效。
2. 当前北京时间、星期和启用状态必须匹配。
3. 当前计划当天尚未运行。
4. 先把“当天已运行”写入 EEPROM。
5. 再检查最短投喂间隔和 24 小时份量上限。
6. 通过后保存份量状态并驱动舵机。

先记录当天已运行，是为了断电恢复后不重复出粮。动作前突然断电时可能漏掉一次，这符合“宁可漏一次，也不重复过量”的安全原则。

## 12. EEPROM 写入策略

每次有效投喂写入一次 EEPROM，普通家用每天写入次数很少。保存内容包括：

- 最近命令 UUID。
- 最近投喂 Unix 时间。
- 24 小时窗口开始时间。
- 窗口累计份量。
- 最多 6 条定时计划及各计划最近运行日期。
- 最近一次计划更新命令 UUID。
- 最近一次计划更新时间，用于阻止多手机旧配置覆盖新配置。
- 魔数和校验值。

如果 EEPROM 数据损坏，固件会重置安全状态。实际鱼粮是否已经投喂无法从损坏状态恢复，遇到异常后应人工检查鱼缸。

## 13. 安全说明

HMAC 能保证命令真实性和完整性，结合时间和 UUID 可以抵御普通伪造与重放。但由于 ESP8266 到 MixIO 使用未加密 MQTT 1883：

- MixIO 用户名和项目密码可能被网络路径观察。
- 状态消息可以被观察或伪造。
- 攻击者可能断开连接或制造消息干扰。
- HMAC 密钥没有发送，因此不能仅凭抓取 MQTT 流量生成新投喂命令。

若需要更强安全性，应使用 TLS MQTT Broker、家庭 VPN、反向隧道或支持安全 WSS 的设备客户端。

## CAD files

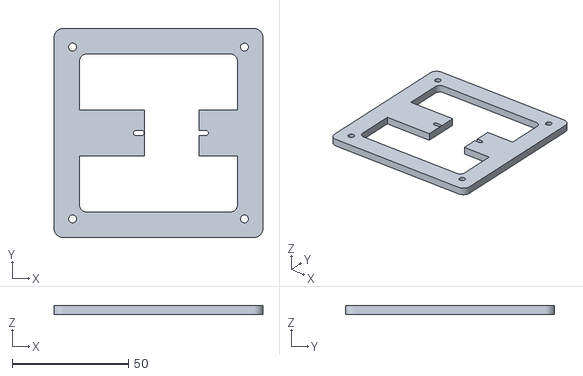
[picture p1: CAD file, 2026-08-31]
mechanical/stl/servo_bracket.stl
90.0 x 90.0 x 4.00

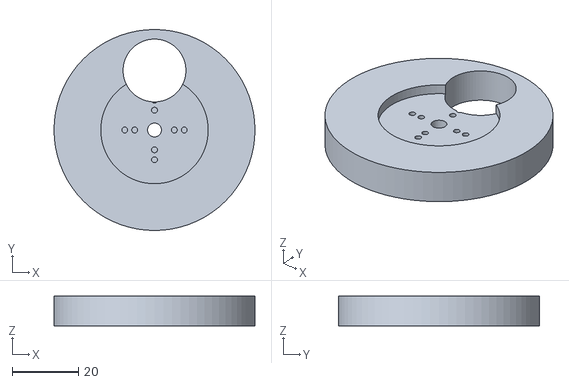
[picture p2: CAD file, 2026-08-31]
mechanical/stl/rotor.stl
60.8 x 60.8 x 9.00

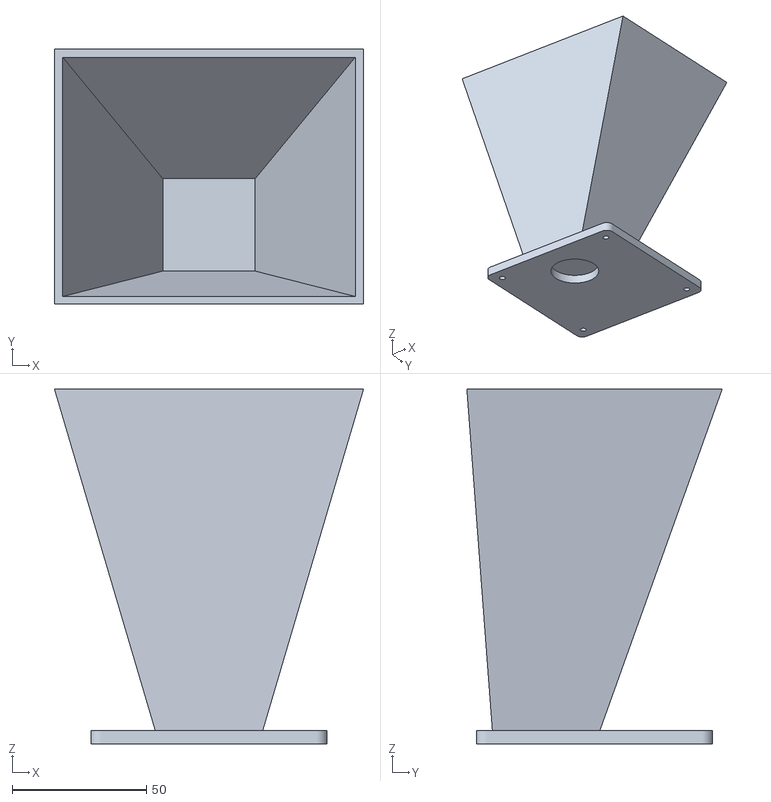
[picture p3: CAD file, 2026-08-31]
mechanical/stl/hopper.stl
115.0 x 95.0 x 132.1

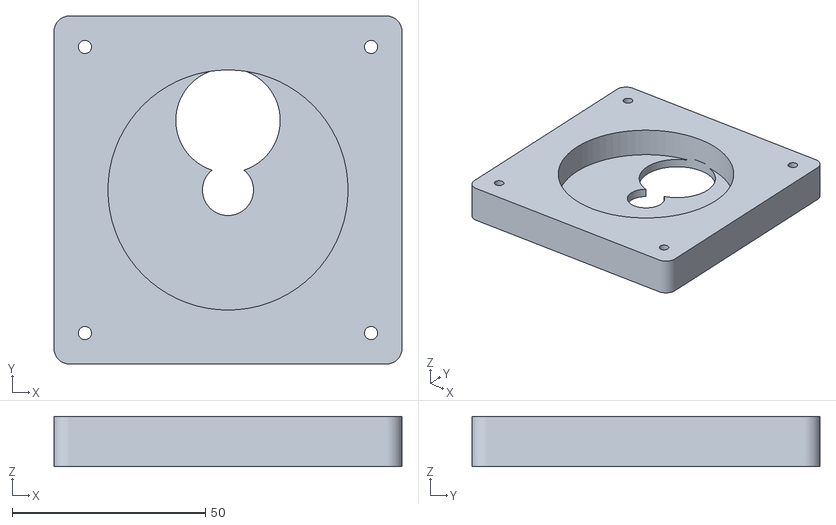
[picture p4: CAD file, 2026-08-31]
mechanical/stl/base.stl
90.0 x 90.0 x 13.0

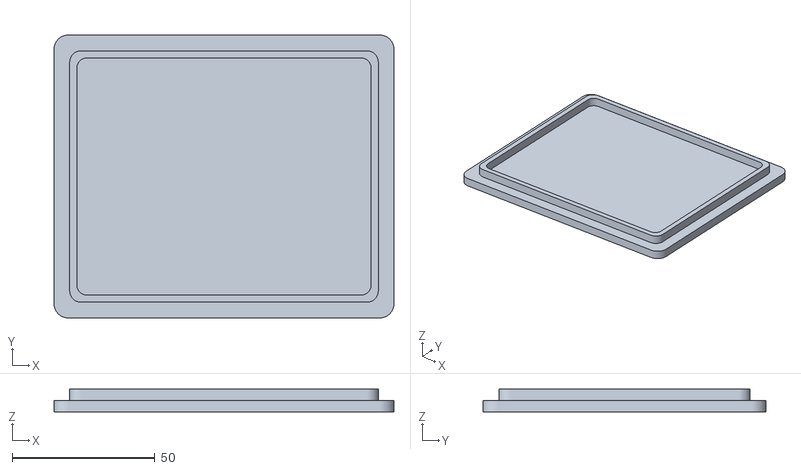
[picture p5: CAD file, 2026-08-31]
mechanical/stl/lid.stl
119.0 x 99.0 x 8.00

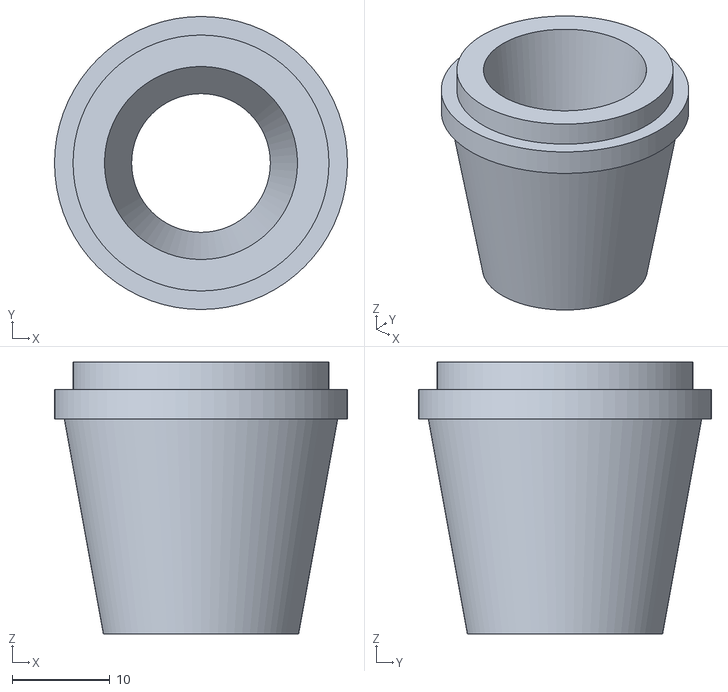
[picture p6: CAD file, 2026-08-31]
mechanical/stl/outlet_chute.stl
30.0 x 30.0 x 27.8

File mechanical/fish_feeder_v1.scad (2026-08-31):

// Fish feeder v2 - SG90 180-degree fixed-volume rotary feeder
// Units: millimetres. Export one printable part at a time with `part`.
// Recommended material: PETG indoors, ASA for outdoor exposure.

$fn = 72;

part = "assembly";
// part values: assembly, base, rotor, hopper, lid, servo_bracket, outlet_chute

wall = 2.8;
base_w = 90;
base_d = 90;
base_h = 13;
axis_x = 45;
axis_y = 45;
rotor_r = 30.4;
chamber_r = 31.05;
rotor_t = 9;
rotor_z = 3.5;
cup_r = 9.5;
cup_offset = 18;
port_r = 13.5;
fill_x = axis_x;
fill_y = axis_y - cup_offset;
drop_x = axis_x;
drop_y = axis_y + cup_offset;
hopper_top_z = 145;

module rounded_box_at(origin, size, radius = 3) {
  translate(origin)
    hull() {
      for (x = [radius, size[0] - radius])
        for (y = [radius, size[1] - radius])
          translate([x, y, 0]) cylinder(r = radius, h = size[2]);
    }
}

module cover_holes(z0 = -1, h = 25, diameter = 3.4) {
  for (x = [8, base_w - 8])
    for (y = [8, base_d - 8])
      translate([x, y, z0]) cylinder(d = diameter, h = h);
}

module base_body() {
  difference() {
    rounded_box_at([0, 0, 0], [base_w, base_d, base_h], 4);

    // Open top: install the rotor, then bolt the hopper flange down as cover.
    translate([axis_x, axis_y, 3]) cylinder(r = chamber_r, h = base_h + 1);

    // Pellet outlet through the 3 mm floor.
    translate([drop_x, drop_y, -1]) cylinder(r = port_r, h = 5);

    // Clearance for the SG90 output boss. The horn sits in the chamber.
    translate([axis_x, axis_y, -1]) cylinder(d = 13.2, h = 6);

    // Long M3 bolts clamp hopper, base and lower frame together.
    cover_holes();

  }
}

module rotor() {
  difference() {
    translate([axis_x, axis_y, rotor_z]) cylinder(r = rotor_r, h = rotor_t);

    // Through pocket: about 2.55 mL before pellet packing effects.
    translate([fill_x, fill_y, rotor_z - 1])
      cylinder(r = cup_r, h = rotor_t + 2);

    // Access to the original horn centre screw.
    translate([axis_x, axis_y, rotor_z - 1]) cylinder(d = 4.2, h = rotor_t + 2);

    // Recess lets the stock SG90 horn sit inside the rotor, leaving only
    // 0.5 mm running clearance between the rotor and the base floor.
    translate([axis_x, axis_y, rotor_z - 0.1]) cylinder(d = 32.5, h = 2.8);

    // Blind pilot holes accept M2 screws from the horn side. Two radii cover
    // the common SG90 round and cross horns without weakening the food face.
    for (radius = [6, 9])
      for (a = [0, 90, 180, 270])
        translate([axis_x + radius * cos(a), axis_y + radius * sin(a), rotor_z - 0.1])
          cylinder(d = 1.8, h = 5);
  }
}

module rect_frustum(center0, center1, z0, z1, bottom_w, bottom_d, top_w, top_d) {
  hull() {
    translate([center0[0] - bottom_w / 2, center0[1] - bottom_d / 2, z0])
      cube([bottom_w, bottom_d, 0.1]);
    translate([center1[0] - top_w / 2, center1[1] - top_d / 2, z1])
      cube([top_w, top_d, 0.1]);
  }
}

module hopper() {
  // The neck is over the home-position pocket; the upper bin shifts to the
  // base centre to keep the assembled feeder balanced.
  difference() {
    rect_frustum([fill_x, fill_y], [axis_x, axis_y], 18, hopper_top_z,
                 40, 40, 115, 95);
    rect_frustum([fill_x, fill_y], [axis_x, axis_y], 18 + wall, hopper_top_z + 1,
                 34.4, 34.4, 109.4, 89.4);
  }

  // The flange is also the removable top plate of the rotor chamber.
  difference() {
    rounded_box_at([1, 1, base_h], [88, 88, 5], 4);
    translate([fill_x, fill_y, base_h - 1]) cylinder(r = port_r, h = 12);
    cover_holes(base_h - 1, 8);
  }
}

module lid() {
  // Overhanging rain lip and an inner locating rim with 0.7 mm clearance.
  rounded_box_at([-14.5, -4.5, hopper_top_z], [119, 99, 4], 5);
  difference() {
    rounded_box_at([-9, 1, hopper_top_z - 4], [108, 88, 5], 4);
    rounded_box_at([-6.5, 3.5, hopper_top_z - 5], [103, 83, 7], 3.5);
  }
}

module servo_bracket() {
  difference() {
    union() {
      // Perimeter frame shares the four main M3 fasteners with the base.
      difference() {
        rounded_box_at([0, 0, -4], [90, 90, 4], 4);
        rounded_box_at([11, 11, -5], [68, 68, 6], 3);
      }

      // Bridges suspend the offset SG90 cradle below the shaft axis.
      translate([8, 35, -4]) cube([31, 20, 4]);
      translate([62.4, 35, -4]) cube([19.6, 20, 4]);
    }

    cover_holes(-5, 7);

    // Servo body passes through from below. The offset follows the real SG90
    // shaft/body relationship; 0.6-1.0 mm total clearance covers common clones.
    translate([39, 38.4, -5]) cube([23.4, 13.2, 6]);

    // Ear slots accept M2 screws and tolerate clone-to-clone hole spacing.
    for (x = [36.5, 64.2])
      hull() {
        translate([x - 1.2, axis_y, -5]) cylinder(d = 2.2, h = 6);
        translate([x + 1.2, axis_y, -5]) cylinder(d = 2.2, h = 6);
      }
  }
}

module outlet_chute() {
  difference() {
    union() {
      // Shoulder sits against the bottom of the base.
      translate([drop_x, drop_y, -3]) cylinder(d = 30, h = 3);
      // Spigot has 0.4 mm radial clearance in the 27 mm outlet.
      translate([drop_x, drop_y, 0]) cylinder(d = 26.2, h = 2.8);
      // Short taper directs pellets clear of the mechanism.
      translate([drop_x, drop_y, -25]) cylinder(d1 = 20, d2 = 28, h = 22);
    }
    translate([drop_x, drop_y, -26]) cylinder(d1 = 14, d2 = 20, h = 30);
  }
}

module sg90_preview() {
  // Nominal reference only; excluded from exported STL files.
  color("#2457a7") translate([39.2, 38.75, -28]) cube([22.8, 12.5, 24]);
  color("#2457a7") translate([34, 37.5, -7]) cube([33, 15, 2.5]);
  color("white") translate([axis_x, axis_y, -4]) cylinder(d = 12, h = 7);
}

module assembly() {
  color("#4d5960") base_body();
  color("#d88742") rotor();
  color("#82a89f", 0.88) hopper();
  color("#a9c1ba", 0.9) lid();
  color("#2f3438") servo_bracket();
  color("#2f3438") outlet_chute();
  sg90_preview();
}

// Support-friendly STL orientations while preserving assembly coordinates.
module rotor_print() {
  translate([-axis_x + rotor_r, axis_y + rotor_r, rotor_z + rotor_t])
    rotate([180, 0, 0]) rotor();
}

module hopper_print() {
  translate([12.5, 2.5, -base_h]) hopper();
}

module lid_print() {
  translate([14.5, 4.5 + 2 * axis_y, hopper_top_z + 4])
    rotate([180, 0, 0]) lid();
}

module servo_bracket_print() {
  translate([0, 0, 4]) servo_bracket();
}

module chute_print() {
  translate([-drop_x + 15, -drop_y + 15, 25]) outlet_chute();
}

if (part == "base") base_body();
else if (part == "rotor") rotor_print();
else if (part == "hopper") hopper_print();
else if (part == "lid") lid_print();
else if (part == "servo_bracket") servo_bracket_print();
else if (part == "outlet_chute") chute_print();
else assembly();

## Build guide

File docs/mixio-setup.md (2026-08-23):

# MixIO 注册、项目和主题配置

## 1. 使用主站账号项目

打开 [MixIO 主站](https://mixio.mixly.cn) 注册并登录。创建一个普通账号项目，例如：

```text
项目名称：fish-feeder
```

不要使用以 `@` 开头的 Mixly Key 公开项目。公开项目只要知道工程名就可能访问或发布主题，不适合远程投喂器。

## 2. 记录三项信息

进入项目后记录：

1. MixIO 用户名。
2. 项目名称。
3. 项目密码。

项目密码用于 MQTT 设备连接，不是账号网页登录密码。网页和 ESP8266 都需要使用同一组用户名、项目名称和项目密码。

不要把账号登录密码、项目密码或命令签名密钥提交到公开 GitHub 仓库。

## 3. 不需要设计 MixIO 页面

本项目不使用 MixIO 自带的按钮、图表和布局。MixIO 只承担 MQTT Broker：

- 自定义网页从 GitHub Pages 加载。
- 网页连接 `wss://mixio.mixly.cn:8084`。
- ESP8266 连接 `mixio.mixly.cn:1883`。
- 双方使用 MQTT 主题直接通信。

因此 MixIO 项目可以保持空白，不需要添加任何组件。

## 4. 本项目主题

假设用户名为 `myname`，项目名为 `fish-feeder`，完整主题如下：

```text
myname/fish-feeder/feeder_cmd
myname/fish-feeder/feeder_ack
myname/fish-feeder/feeder_state
myname/fish-feeder/feeder_online
myname/fish-feeder/feeder_query
```

固件和网页会自动拼接主题，不需要在 MixIO 后台手工创建。

## 5. 创建命令签名密钥

自定义网页第一次打开时会显示连接设置：

1. 填写 MixIO 用户名。
2. 填写项目名。
3. 填写项目密码。
4. 点击“生成”创建 48 位十六进制签名密钥。
5. 点击“复制”。
6. 把它写入 ESP8266 `config.h` 的 `COMMAND_SECRET`。

示例：

```cpp
#define COMMAND_SECRET "8d2f...此处应为你自己生成的随机值...2a19"
```

网页和固件必须完全一致，包括大小写。这个密钥不会发送给 MixIO；网页只发送命令和 HMAC 签名。

## 6. 免费层消息频率

MixIO 官方开源配置的默认限制包括每用户每秒最多 5 条消息、最多 20 个项目和最多 1000 条离线存储消息。主站生产配置可能调整，以实际服务为准。

本项目正常流量很低：

- 设备每 60 秒发布一次状态。
- 手机只在打开页面时订阅消息。
- 每次投喂产生一条命令和约两条确认。

这远低于教育项目常用的消息频率。不要把状态上报周期设置成 1 秒以内。

## 7. 连接端口与安全性

| 客户端 | 地址 | 加密 |
|---|---|---|
| 自定义网页 | `wss://mixio.mixly.cn:8084` | 是 |
| ESP8266 PubSubClient | `mixio.mixly.cn:1883` | 否 |

ESP8266 端使用 1883 时，MixIO 项目凭据和状态消息不具备传输保密性。项目通过额外 HMAC 签名确保投喂命令不能被随意伪造，但商业产品或高安全场景应更换为 TLS MQTT 或私有安全 Broker。

## 8. 常见问题

### 网页显示 MixIO 连接失败

- 检查项目密码，不是账号登录密码。
- 检查用户名和项目名是否区分大小写。
- 确认手机网络没有封锁 8084 WebSocket 端口。
- 尝试在家庭 Wi-Fi 和手机流量之间切换测试。

### 网页连接成功但设备离线

- 检查 ESP8266 是否连接 2.4GHz Wi-Fi。
- 查看串口中的 MQTT 状态码。
- 确认固件中的用户名、项目名和项目密码与网页一致。
- 确认 `DEVICE_ID` 只用于显示，不影响主题拼接。

### 能看到状态但命令被拒绝

- 网页和固件的 `COMMAND_SECRET` 不一致。
- ESP8266 尚未完成 NTP 时间同步。
- 距上次投喂不足安全间隔。
- 24 小时份量达到上限。

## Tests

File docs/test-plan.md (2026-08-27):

# 测试与验收清单

## 1. 电气测试

- [ ] NodeMCU USB 烧录稳定，串口没有反复重启。
- [ ] 舵机使用外部 5V 电源，不接 ESP8266 3.3V。
- [ ] NodeMCU 与舵机电源共地。
- [ ] 舵机附近安装 470～1000uF 电容。
- [ ] 舵机启动时 5V 电压没有明显跌落。
- [ ] 连续动作 20 次，NodeMCU 不重启。

## 2. 舵机与机械测试

- [ ] 上电后量杯处于关闭/装粮位置。
- [ ] 一份命令只完成一次打开—关闭循环。
- [ ] 两份和三份分别完成对应次数循环。
- [ ] 舵机不会撞击机械限位或持续嗡鸣。
- [ ] 连续模式上电后舵机保持停止，正转/反转方向和停止脉宽校准正确。
- [ ] 连续模式按目标角度和一圈耗时运行，180°、360°各测试至少10次并记录误差。
- [ ] 定位模式修改关闭/投喂角度后，设备回报值与空载实测一致；不测试超过180°。
- [ ] 空载连续运行 100 次无卡死。
- [ ] 装粮连续运行 100 次无明显漏投或双投。
- [ ] 20 次单份称重的误差满足实际养鱼需求。
- [ ] 粮仓盖、防潮和出粮口位置合理。

## 3. 网络连接测试

- [ ] ESP8266 能连接家庭 2.4GHz Wi-Fi。
- [ ] 串口显示 MixIO MQTT connected。
- [ ] 网页通过家庭 Wi-Fi 连接 MixIO。
- [ ] 网页通过手机 4G/5G 连接 MixIO。
- [ ] 网页能立即读取保留的设备状态。
- [ ] 路由器重启后 ESP8266 自动恢复连接。
- [ ] 手机网络切换后网页自动重连。

## 4. 命令安全测试

- [ ] 正确签名命令可以执行。
- [ ] 修改网页签名密钥后命令被 `invalid_signature` 拒绝。
- [ ] 重复发送同一个 UUID 不会再次动作。
- [ ] 超过 45 秒的命令被 `command_expired` 拒绝。
- [ ] ESP8266 尚未同步时间时不接受远程投喂。
- [ ] 一分钟内第二次投喂被 `cooldown` 拒绝。
- [ ] 达到 24 小时份量上限后继续命令被 `daily_limit` 拒绝。
- [ ] 修改每日最大次数后，第 N+1 次命令被 `daily_limit` 拒绝；断电重启后计数仍保留。
- [ ] 修改最短间隔后，间隔内重复命令被 `cooldown` 拒绝。

## 5. 断电和故障测试

- [ ] 正常待机时断电，恢复后不会自动投喂。
- [ ] 收到命令但舵机动作前断电，恢复后相同 UUID 不会重跑。
- [ ] 舵机动作期间断电，恢复后不会再次执行相同命令。
- [ ] ESP8266 离线时网页投喂按钮不可用。
- [ ] 设备意外掉线后网页收到离线遗嘱或在 180 秒内状态超时。
- [ ] 页面等待确认超时后提示人工检查，而不是自动重试。

## 6. 定时计划测试

- [ ] 可以新增、编辑、停用、启用和删除计划。
- [ ] 计划重新读取后与网页保存内容一致。
- [ ] 网页关闭、手机锁屏后计划仍按北京时间执行。
- [ ] 周一到周五、周末和自定义星期掩码分别正确。
- [ ] 相同日期和时间的冲突计划被网页阻止。
- [ ] 手动投喂后一分钟内到期的计划被安全间隔跳过。
- [ ] 达到 24 小时份量上限后，计划不会继续出粮。
- [ ] 计划执行时断电，恢复后当天不会再次执行同一条计划。
- [ ] 设备完成过 NTP 校时后，MixIO 临时不可达时计划仍能执行。
- [ ] 设备冷启动且无法校时时，不会使用错误时间盲目投喂。

## 7. 长期运行测试

- [ ] 连续上电 24 小时无内存持续下降。
- [ ] 连续上电 7 天无异常重启。
- [ ] 每天按计划进行数次自动投喂。
- [ ] MixIO 暂时不可达时仅执行已保存的本地计划，不接受新远程命令。
- [ ] 网络恢复后只处理新鲜且有效的命令。
- [ ] 舵机和电源在封闭外壳内温度可接受。

## 8. 上线验收条件

必须同时满足：

1. 100 次装粮动作没有危险的重复投喂。
2. 断电、重启和 MQTT 重连不会自动触发旧命令。
3. 手机流量下至少完成 10 次端到端测试。
4. 投喂份量已经称重校准。
5. 供电、外壳和固定方式适合鱼缸潮湿环境。
6. 用户理解“completed 只代表舵机完成”，没有落料传感器时仍需定期检查。
7. 定时计划经过至少 7 天闭屏运行和一次断电恢复测试。

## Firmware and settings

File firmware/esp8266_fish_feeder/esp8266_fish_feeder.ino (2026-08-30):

#include <Arduino.h>
#include <ArduinoJson.h>
#include <DNSServer.h>
#include <EEPROM.h>
#include <ESP8266WiFi.h>
#include <ESP8266WebServer.h>
#include <ESP8266mDNS.h>
#include <PubSubClient.h>
#include <Servo.h>
#include <stddef.h>
#include <time.h>

extern "C" {
#include <bearssl/bearssl.h>
}

#include "config.h"

#if !CONFIGURED
#error "Edit config.h, replace every placeholder, then set CONFIGURED to 1."
#endif

static_assert(sizeof(COMMAND_SECRET) - 1 >= 24, "COMMAND_SECRET must contain at least 24 characters.");
static_assert(
  MIN_FEED_INTERVAL_SECONDS >= COMMAND_MAX_AGE_SECONDS,
  "MIN_FEED_INTERVAL_SECONDS must be at least COMMAND_MAX_AGE_SECONDS."
);

static const char *FIRMWARE_VERSION = "1.5.3";
static const uint32_t SAFETY_MAGIC = 0x46454548UL;
static const uint32_t WIFI_CONFIG_MAGIC = 0x57494649UL;
static const uint32_t DOUBLE_RESET_MAGIC = 0x44525354UL;
static const uint16_t EEPROM_BYTES = 512;
static const uint16_t WIFI_CONFIG_OFFSET = 256;
static const uint32_t DOUBLE_RESET_WINDOW_MS = 8000UL;

struct ScheduleEntry {
  uint8_t enabled;
  uint8_t hour;
  uint8_t minute;
  uint8_t portion;
  uint8_t daysMask;
  uint32_t lastRunLocalDay;
};

struct PersistedSafetyState {
  uint32_t magic;
  char lastCommandId[37];
  char lastScheduleCommandId[37];
  char lastConfigCommandId[37];
  uint32_t lastFeedAt;
  uint32_t windowStartAt;
  uint16_t portionsInWindow;
  uint16_t feedsInWindow;
  uint8_t scheduleCount;
  uint32_t lastScheduleIssuedAt;
  uint32_t lastConfigIssuedAt;
  uint8_t servoMode;
  uint16_t servoClosedAngle;
  uint16_t servoOpenAngle;
  uint16_t continuousTurnDegrees;
  uint32_t continuousMsPerRev;
  uint16_t continuousForwardUs;
  uint16_t continuousReverseUs;
  uint16_t continuousStopUs;
  uint8_t continuousDirection;
  uint8_t continuousReturn;
  uint16_t positionalMoveMs;
  uint16_t actionPauseMs;
  uint16_t positionalReturnMs;
  uint32_t minFeedIntervalSeconds;
  uint16_t maxPortionsPer24h;
  uint16_t maxFeedsPer24h;
  ScheduleEntry schedules[MAX_SCHEDULES];
  uint16_t checksum;
};

struct PersistedWifiConfig {
  uint32_t magic;
  char ssid[33];
  char password[65];
  uint16_t checksum;
};

static_assert(sizeof(PersistedSafetyState) <= EEPROM_BYTES, "Persisted state exceeds EEPROM allocation.");
static_assert(sizeof(PersistedSafetyState) <= WIFI_CONFIG_OFFSET, "Persisted state overlaps Wi-Fi configuration.");
static_assert(WIFI_CONFIG_OFFSET + sizeof(PersistedWifiConfig) <= EEPROM_BYTES, "Wi-Fi config exceeds EEPROM allocation.");

WiFiClient networkClient;
PubSubClient mqttClient(networkClient);
Servo feederServo;
PersistedSafetyState safetyState;
PersistedWifiConfig wifiConfig;
ESP8266WebServer configServer(80);
DNSServer dnsServer;

String commandTopic;
String acknowledgementTopic;
String stateTopic;
String onlineTopic;
String queryTopic;
String lastError;
String lastFeedSource;
String lastServoTestCommandId;
String lastServoTestStatus;
String lastCompletedFeedCommandId;
String pendingCommandBody;

uint32_t lastMqttAttemptAt = 0;
uint32_t lastStatePublishAt = 0;
uint32_t lastScheduleMinute = 0xFFFFFFFFUL;
bool clockWasReady = false;
bool configPortalActive = false;
bool configServerStarted = false;
bool mdnsStarted = false;
bool stateQueryPending = false;
uint32_t restartAt = 0;
uint32_t doubleResetMarkerSetAt = 0;

enum ServoMotionSource : uint8_t {
  MOTION_SOURCE_NONE = 0,
  MOTION_SOURCE_MANUAL = 1,
  MOTION_SOURCE_TEST = 2,
  MOTION_SOURCE_SCHEDULE = 3
};

enum ServoMotionPhase : uint8_t {
  MOTION_PHASE_IDLE = 0,
  MOTION_PHASE_PREPARE,
  MOTION_PHASE_FORWARD,
  MOTION_PHASE_PAUSE,
  MOTION_PHASE_RETURN,
  MOTION_PHASE_SETTLE
};

struct ServoMotionJob {
  ServoMotionSource source;
  ServoMotionPhase phase;
  String commandId;
  uint32_t phaseStartedAt;
  uint32_t phaseDurationMs;
  uint32_t lastStepAt;
  uint32_t continuousRunMs;
  uint16_t driveUs;
  uint16_t returnUs;
};

ServoMotionJob servoMotion{MOTION_SOURCE_NONE, MOTION_PHASE_IDLE, "", 0, 0, 0, 0, 0, 0};

struct ResetMarker {
  uint32_t magic;
  uint32_t checksum;
};

uint32_t resetMarkerChecksum(uint32_t magic) {
  return magic ^ 0xA55AA55AUL;
}

bool consumeDoubleResetMarker() {
  ResetMarker marker;
  if (!ESP.rtcUserMemoryRead(0, reinterpret_cast<uint32_t *>(&marker), sizeof(marker))) return false;
  const bool detected = marker.magic == DOUBLE_RESET_MAGIC && marker.checksum == resetMarkerChecksum(marker.magic);
  memset(&marker, 0, sizeof(marker));
  ESP.rtcUserMemoryWrite(0, reinterpret_cast<uint32_t *>(&marker), sizeof(marker));
  return detected;
}

void writeDoubleResetMarker() {
  ResetMarker marker{DOUBLE_RESET_MAGIC, resetMarkerChecksum(DOUBLE_RESET_MAGIC)};
  ESP.rtcUserMemoryWrite(0, reinterpret_cast<uint32_t *>(&marker), sizeof(marker));
}

void clearDoubleResetMarker() {
  ResetMarker marker{0, 0};
  ESP.rtcUserMemoryWrite(0, reinterpret_cast<uint32_t *>(&marker), sizeof(marker));
}

bool due(uint32_t now, uint32_t previous, uint32_t interval) {
  return static_cast<uint32_t>(now - previous) >= interval;
}

uint16_t calculateChecksum(const PersistedSafetyState &value) {
  const uint8_t *bytes = reinterpret_cast<const uint8_t *>(&value);
  uint16_t checksum = 0xA5A5;
  for (size_t i = 0; i < offsetof(PersistedSafetyState, checksum); ++i) {
    checksum = static_cast<uint16_t>((checksum << 5) | (checksum >> 11));
    checksum ^= bytes[i];
  }
  return checksum;
}

uint16_t calculateWifiChecksum(const PersistedWifiConfig &value) {
  const uint8_t *bytes = reinterpret_cast<const uint8_t *>(&value);
  uint16_t checksum = 0x5AA5;
  for (size_t i = 0; i < offsetof(PersistedWifiConfig, checksum); ++i) {
    checksum = static_cast<uint16_t>((checksum << 5) | (checksum >> 11));
    checksum ^= bytes[i];
  }
  return checksum;
}

bool hasStoredWifi() {
  return wifiConfig.magic == WIFI_CONFIG_MAGIC &&
    wifiConfig.ssid[0] != '\0' &&
    wifiConfig.checksum == calculateWifiChecksum(wifiConfig);
}

void clearWifiConfig() {
  memset(&wifiConfig, 0, sizeof(wifiConfig));
  EEPROM.put(WIFI_CONFIG_OFFSET, wifiConfig);
  EEPROM.commit();
}

void saveWifiConfig(const String &ssid, const String &password) {
  memset(&wifiConfig, 0, sizeof(wifiConfig));
  wifiConfig.magic = WIFI_CONFIG_MAGIC;
  ssid.substring(0, sizeof(wifiConfig.ssid) - 1).toCharArray(wifiConfig.ssid, sizeof(wifiConfig.ssid));
  password.substring(0, sizeof(wifiConfig.password) - 1).toCharArray(wifiConfig.password, sizeof(wifiConfig.password));
  wifiConfig.checksum = calculateWifiChecksum(wifiConfig);
  EEPROM.put(WIFI_CONFIG_OFFSET, wifiConfig);
  EEPROM.commit();
}

String configuredSsid() {
  if (hasStoredWifi()) return String(wifiConfig.ssid);
  return String(WIFI_SSID);
}

String configuredPassword() {
  if (hasStoredWifi()) return String(wifiConfig.password);
  return String(WIFI_PASSWORD);
}

String htmlEscape(const String &value) {
  String escaped;
  escaped.reserve(value.length() + 16);
  for (size_t i = 0; i < value.length(); ++i) {
    switch (value[i]) {
      case '&': escaped += F("&amp;"); break;
      case '<': escaped += F("&lt;"); break;
      case '>': escaped += F("&gt;"); break;
      case '"': escaped += F("&quot;"); break;
      case '\'': escaped += F("&#39;"); break;
      default: escaped += value[i]; break;
    }
  }
  return escaped;
}

bool hasConfiguredWifi() {
  return configuredSsid().length() > 0;
}

void saveSafetyState() {
  safetyState.magic = SAFETY_MAGIC;
  safetyState.checksum = calculateChecksum(safetyState);
  EEPROM.put(0, safetyState);
  EEPROM.commit();
}

void resetSafetyState(uint32_t now = 0) {
  memset(&safetyState, 0, sizeof(safetyState));
  safetyState.magic = SAFETY_MAGIC;
  safetyState.windowStartAt = now;
  safetyState.servoClosedAngle = SERVO_CLOSED_ANGLE;
  safetyState.servoOpenAngle = SERVO_OPEN_ANGLE;
  safetyState.servoMode = SERVO_MODE_DEFAULT;
  safetyState.continuousTurnDegrees = SERVO_CONTINUOUS_TURN_DEGREES;
  safetyState.continuousMsPerRev = SERVO_CONTINUOUS_MS_PER_REV;
  safetyState.continuousForwardUs = SERVO_CONTINUOUS_FORWARD_US;
  safetyState.continuousReverseUs = SERVO_CONTINUOUS_REVERSE_US;
  safetyState.continuousStopUs = SERVO_CONTINUOUS_STOP_US;
  safetyState.continuousDirection = 0;
  safetyState.continuousReturn = 1;
  safetyState.positionalMoveMs = SERVO_POSITIONAL_MOVE_MS;
  safetyState.actionPauseMs = SERVO_ACTION_PAUSE_MS;
  safetyState.positionalReturnMs = SERVO_POSITIONAL_RETURN_MS;
  safetyState.minFeedIntervalSeconds = MIN_FEED_INTERVAL_SECONDS;
  safetyState.maxPortionsPer24h = MAX_PORTIONS_PER_24H;
  safetyState.maxFeedsPer24h = DEFAULT_MAX_FEEDS_PER_24H;
  saveSafetyState();
}

void loadSafetyState() {
  EEPROM.begin(EEPROM_BYTES);
  EEPROM.get(0, safetyState);
  EEPROM.get(WIFI_CONFIG_OFFSET, wifiConfig);
  if (
    safetyState.magic != SAFETY_MAGIC ||
    safetyState.scheduleCount > MAX_SCHEDULES ||
    safetyState.servoMode > 1 ||
    safetyState.servoClosedAngle > 180 ||
    safetyState.servoOpenAngle > 180 ||
    (safetyState.servoMode == 0 && safetyState.servoClosedAngle == safetyState.servoOpenAngle) ||
    safetyState.continuousTurnDegrees > 360 ||
    safetyState.continuousMsPerRev < 250 ||
    safetyState.continuousMsPerRev > 10000UL ||
    safetyState.continuousForwardUs < 1000 || safetyState.continuousForwardUs > 2000 ||
    safetyState.continuousReverseUs < 1000 || safetyState.continuousReverseUs > 2000 ||
    safetyState.continuousStopUs < 1400 || safetyState.continuousStopUs > 1600 ||
    safetyState.continuousDirection > 1 ||
    safetyState.continuousReturn > 1 ||
    safetyState.positionalMoveMs < 100 || safetyState.positionalMoveMs > 10000UL ||
    safetyState.actionPauseMs > 10000UL ||
    safetyState.positionalReturnMs < 100 || safetyState.positionalReturnMs > 10000UL ||
    safetyState.minFeedIntervalSeconds < 10 ||
    safetyState.minFeedIntervalSeconds > 86400UL ||
    safetyState.maxPortionsPer24h < 1 ||
    safetyState.maxPortionsPer24h > 300 ||
    safetyState.maxFeedsPer24h < 1 ||
    safetyState.maxFeedsPer24h > 100 ||
    safetyState.checksum != calculateChecksum(safetyState)
  ) {
    resetSafetyState();
  }
}

uint32_t epochNow() {
  const time_t current = time(nullptr);
  return current > 0 ? static_cast<uint32_t>(current) : 0;
}

bool clockReady() {
  return epochNow() > 1700000000UL;
}

void startClockSync() {
  configTime(0, 0, "ntp.aliyun.com", "ntp1.aliyun.com", "pool.ntp.org");
}

String topicFor(const char *name) {
  return String(MIXIO_USERNAME) + "/" + MIXIO_PROJECT + "/" + name;
}

String bytesToHex(const uint8_t *bytes, size_t length) {
  static const char hex[] = "0123456789abcdef";
  String output;
  output.reserve(length * 2);
  for (size_t i = 0; i < length; ++i) {
    output += hex[(bytes[i] >> 4) & 0x0F];
    output += hex[bytes[i] & 0x0F];
  }
  return output;
}

String hmacSha256(const String &secret, const String &message) {
  br_hmac_key_context keyContext;
  br_hmac_context context;
  uint8_t output[32];
  br_hmac_key_init(
    &keyContext,
    &br_sha256_vtable,
    reinterpret_cast<const void *>(secret.c_str()),
    secret.length()
  );
  br_hmac_init(&context, &keyContext, sizeof(output));
  br_hmac_update(&context, reinterpret_cast<const void *>(message.c_str()), message.length());
  br_hmac_out(&context, output);
  return bytesToHex(output, sizeof(output));
}

bool constantTimeEquals(const String &left, const String &right) {
  if (left.length() != right.length()) return false;
  uint8_t difference = 0;
  for (size_t i = 0; i < left.length(); ++i) difference |= left[i] ^ right[i];
  return difference == 0;
}

bool validCommandId(const String &value) {
  if (value.length() != 36) return false;
  for (size_t i = 0; i < value.length(); ++i) {
    const char c = value[i];
    const bool dash = i == 8 || i == 13 || i == 18 || i == 23;
    if (dash && c != '-') return false;
    if (!dash && !isxdigit(static_cast<unsigned char>(c))) return false;
  }
  return true;
}

bool publishJson(const String &topic, JsonDocument &document, bool retained = false) {
  String payload;
  serializeJson(document, payload);
  return mqttClient.publish(topic.c_str(), payload.c_str(), retained);
}

void publishAcknowledgement(
  const String &commandId,
  const char *status,
  int portion,
  const char *reason,
  const char *action = "feed"
) {
  StaticJsonDocument<384> document;
  document["v"] = 1;
  document["id"] = commandId;
  document["device_id"] = DEVICE_ID;
  document["action"] = action;
  document["status"] = status;
  document["portion"] = portion;
  document["reason"] = reason;
  document["ts"] = epochNow();
  publishJson(acknowledgementTopic, document, false);
}

void refreshRollingWindow(uint32_t now) {
  if (
    safetyState.windowStartAt == 0 ||
    now < safetyState.windowStartAt ||
    now - safetyState.windowStartAt >= 86400UL
  ) {
    safetyState.windowStartAt = now;
    safetyState.portionsInWindow = 0;
    safetyState.feedsInWindow = 0;
    saveSafetyState();
  }
}

void publishState() {
  const uint32_t now = epochNow();
  if (now > 0) refreshRollingWindow(now);

  StaticJsonDocument<1792> document;
  document["v"] = 1;
  document["online"] = true;
  document["device_id"] = DEVICE_ID;
  document["firmware"] = FIRMWARE_VERSION;
  document["rssi"] = WiFi.RSSI();
  document["ip"] = WiFi.localIP().toString();
  document["wifi_ssid"] = WiFi.SSID();
  document["config_url"] = String("http://") + WiFi.localIP().toString() + "/";
  document["free_heap"] = ESP.getFreeHeap();
  document["uptime_s"] = millis() / 1000UL;
  document["ts"] = now;
  document["clock_ready"] = clockReady();
  document["last_feed_at"] = safetyState.lastFeedAt;
  document["portions_24h"] = safetyState.portionsInWindow;
  document["feeds_24h"] = safetyState.feedsInWindow;
  document["max_portions_24h"] = safetyState.maxPortionsPer24h;
  document["max_feeds_24h"] = safetyState.maxFeedsPer24h;
  document["min_interval_seconds"] = safetyState.minFeedIntervalSeconds;
  document["servo_closed_angle"] = safetyState.servoClosedAngle;
  document["servo_open_angle"] = safetyState.servoOpenAngle;
  document["servo_travel_degrees"] = abs(static_cast<int>(safetyState.servoOpenAngle) - static_cast<int>(safetyState.servoClosedAngle));
  document["servo_mode"] = safetyState.servoMode;
  document["continuous_turn_degrees"] = safetyState.continuousTurnDegrees;
  document["continuous_ms_per_rev"] = safetyState.continuousMsPerRev;
  document["continuous_forward_us"] = safetyState.continuousForwardUs;
  document["continuous_reverse_us"] = safetyState.continuousReverseUs;
  document["continuous_stop_us"] = safetyState.continuousStopUs;
  document["continuous_direction"] = safetyState.continuousDirection;
  document["continuous_return"] = safetyState.continuousReturn == 1;
  document["positional_move_ms"] = safetyState.positionalMoveMs;
  document["action_pause_ms"] = safetyState.actionPauseMs;
  document["positional_return_ms"] = safetyState.positionalReturnMs;
  document["last_config_command_id"] = safetyState.lastConfigCommandId;
  document["last_servo_test_command_id"] = lastServoTestCommandId;
  document["last_servo_test_status"] = lastServoTestStatus;
  document["last_completed_feed_command_id"] = lastCompletedFeedCommandId;
  document["reset_reason"] = ESP.getResetReason();
  document["last_error"] = lastError;
  document["last_feed_source"] = lastFeedSource;
  document["timezone_offset_minutes"] = TIMEZONE_OFFSET_SECONDS / 60UL;

  JsonArray schedules = document.createNestedArray("schedules");
  for (uint8_t i = 0; i < safetyState.scheduleCount && i < MAX_SCHEDULES; ++i) {
    const ScheduleEntry &schedule = safetyState.schedules[i];
    JsonObject item = schedules.createNestedObject();
    item["enabled"] = schedule.enabled == 1;
    item["hour"] = schedule.hour;
    item["minute"] = schedule.minute;
    item["portion"] = schedule.portion;
    item["days_mask"] = schedule.daysMask;
  }
  publishJson(stateTopic, document, true);
}

void publishOnline(bool online) {
  StaticJsonDocument<192> document;
  document["v"] = 1;
  document["online"] = online;
  document["device_id"] = DEVICE_ID;
  document["ts"] = epochNow();
  publishJson(onlineTopic, document, true);
}

void attachFeederServo() {
  if (safetyState.servoMode == 0) {
    feederServo.attach(
      SERVO_PIN,
      SERVO_POSITIONAL_MIN_US,
      SERVO_POSITIONAL_MAX_US,
      safetyState.servoClosedAngle
    );
  } else {
    feederServo.attach(SERVO_PIN, 500, 2400, safetyState.continuousStopUs);
  }
}

bool servoMotionActive() {
  return servoMotion.source != MOTION_SOURCE_NONE;
}

void setServoMotionPhase(ServoMotionPhase phase, uint32_t durationMs) {
  servoMotion.phase = phase;
  servoMotion.phaseStartedAt = millis();
  servoMotion.phaseDurationMs = durationMs;
  servoMotion.lastStepAt = servoMotion.phaseStartedAt;
}

void finishServoMotion(bool completed) {
  if (feederServo.attached()) feederServo.detach();
  const ServoMotionSource source = servoMotion.source;
  const String commandId = servoMotion.commandId;
  servoMotion.source = MOTION_SOURCE_NONE;
  servoMotion.phase = MOTION_PHASE_IDLE;
  servoMotion.commandId = "";

  if (source == MOTION_SOURCE_TEST) {
    lastServoTestStatus = completed ? "completed" : "failed";
    lastError = completed ? "" : "servo_failed";
    publishAcknowledgement(
      commandId,
      completed ? "completed" : "failed",
      1,
      completed ? "servo_test_completed" : "servo_failed",
      "servo_test"
    );
  } else if (source == MOTION_SOURCE_MANUAL) {
    lastError = completed ? "" : "servo_failed";
    if (completed) {
      lastFeedSource = "manual";
      lastCompletedFeedCommandId = commandId;
    }
    publishAcknowledgement(
      commandId,
      completed ? "completed" : "failed",
      1,
      completed ? "motor_sequence_completed" : "servo_failed"
    );
  } else if (source == MOTION_SOURCE_SCHEDULE) {
    lastError = completed ? "" : "servo_failed";
    if (completed) lastFeedSource = "schedule";
  }
  publishState();
}

bool startServoMotion(ServoMotionSource source, const String &commandId = "") {
  if (servoMotionActive()) return false;
  Serial.printf(
    "Servo sequence: mode=%u closed=%u open=%u\n",
    safetyState.servoMode,
    safetyState.servoClosedAngle,
    safetyState.servoOpenAngle
  );

  servoMotion.source = source;
  servoMotion.commandId = commandId;
  attachFeederServo();
  if (!feederServo.attached()) {
    Serial.println("Servo attach failed");
    servoMotion.source = MOTION_SOURCE_NONE;
    servoMotion.commandId = "";
    return false;
  }

  if (safetyState.servoMode == 1) {
    const uint32_t calculatedRunMs =
      (static_cast<uint32_t>(safetyState.continuousTurnDegrees) * safetyState.continuousMsPerRev) / 360UL;
    servoMotion.continuousRunMs = calculatedRunMs < 50UL ? 50UL : calculatedRunMs;
    servoMotion.driveUs = safetyState.continuousDirection == 1
      ? safetyState.continuousReverseUs
      : safetyState.continuousForwardUs;
    servoMotion.returnUs = safetyState.continuousDirection == 1
      ? safetyState.continuousForwardUs
      : safetyState.continuousReverseUs;
    feederServo.writeMicroseconds(safetyState.continuousStopUs);
    setServoMotionPhase(MOTION_PHASE_PREPARE, 120UL);
    return true;
  }

  feederServo.write(safetyState.servoClosedAngle);
  setServoMotionPhase(MOTION_PHASE_PREPARE, 250UL);
  return true;
}
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
void loop() {
  serviceServoMotion();
  if (!configPortalActive && doubleResetMarkerSetAt != 0 && due(millis(), doubleResetMarkerSetAt, DOUBLE_RESET_WINDOW_MS)) {
    clearDoubleResetMarker();
    doubleResetMarkerSetAt = 0;
  }
  checkSchedules();
  if (configPortalActive) {
    serviceConfigPortal();
    return;
  }
  serviceConfigServer();
  if (!ensureWiFi()) {
    delay(1000);
    return;
  }
  if (!connectMqtt()) {
    delay(20);
    return;
  }

  mqttClient.loop();
  if (stateQueryPending) {
    stateQueryPending = false;
    publishState();
  }
  processPendingMqttCommand();
  const uint32_t now = millis();
  const bool timeIsReady = clockReady();
  if (timeIsReady && !clockWasReady) {
    clockWasReady = true;
    publishOnline(true);
    publishState();
  }
  if (due(now, lastStatePublishAt, STATE_PUBLISH_INTERVAL_MS)) {
    lastStatePublishAt = now;
    publishState();
  }
  delay(10);
}

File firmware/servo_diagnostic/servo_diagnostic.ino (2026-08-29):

#include <Arduino.h>
#include <Servo.h>

// NodeMCU D1 is GPIO5. Power the servo from a separate regulated 5V supply,
// and connect the supply GND to NodeMCU GND.
static const uint8_t SERVO_SIGNAL_PIN = D1;
static const uint16_t POSITION_MIN_US = 500;
static const uint16_t POSITION_CENTER_US = 1500;
static const uint16_t POSITION_MAX_US = 2400;
static const uint32_t HOLD_MS = 1800;

Servo testServo;

void moveTo(uint16_t pulseUs, const char *label) {
  Serial.printf("Move to %s: %u us\n", label, pulseUs);
  testServo.writeMicroseconds(pulseUs);
  delay(HOLD_MS);
}

void setup() {
  Serial.begin(115200);
  Serial.println();
  Serial.println("SG90 direct diagnostic starting");
  testServo.attach(SERVO_SIGNAL_PIN, POSITION_MIN_US, POSITION_MAX_US);

  if (!testServo.attached()) {
    Serial.println("ERROR: Servo attach failed");
    return;
  }

  moveTo(POSITION_CENTER_US, "center");
}

void loop() {
  if (!testServo.attached()) {
    delay(1000);
    return;
  }

  moveTo(POSITION_MIN_US, "minimum");
  moveTo(POSITION_CENTER_US, "center");
  moveTo(POSITION_MAX_US, "maximum");
  moveTo(POSITION_CENTER_US, "center");
}

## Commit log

2026-08-27 Support continuous and positional servo modes
2026-08-28 Accept legacy servo configuration payloads
2026-08-28 Add servo diagnostics and test command
2026-08-29 Add configurable servo motion sequences
2026-08-30 Fix servo test settings and acknowledgements
    [app.js, esp8266_fish_feeder.ino]
2026-08-30 Fix servo resets and config confirmation
    [app.js, esp8266_fish_feeder.ino]
2026-08-30 Make servo actions nonblocking and feed once
2026-08-31 Add printable SG90 dosing hopper design
    [fish_feeder_v1.scad]
2026-08-31 Add validated printable SG90 feeder STL set
    [base.stl, fish_feeder_v1.scad, hopper.stl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]
